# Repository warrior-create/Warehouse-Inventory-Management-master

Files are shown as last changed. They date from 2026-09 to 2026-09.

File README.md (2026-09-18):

# 🏭 Warehouse Inventory Management Robot

<div align="center">








**Problem Statement : Autonomous Inventory Management**

*A 4WD Mecanum Robot for Autonomous Navigation, QR Scanning, and Real-Time Inventory Logging*

</div>

---

## 📹 Demo Videos

<!-- 
INSTRUCTIONS: Replace the placeholder paths below with your actual video files or YouTube links.
For local files: Place videos in a 'media/' folder and use relative paths.
For YouTube: Use the embed format shown in the comments.
-->

<div align="center">

| 🎬 Hardware Navigation | 🤖 MPPI Controller |
|:---:|:---:|
| Hardware Navigation (https://drive.google.com/file/d/1SxE7VbpoMyJDe-7mRSphyiXIrN796s2v/view?usp=sharing) | MPPI Demo (https://drive.google.com/file/d/1yMgr9xhQmlWIOJ6BMVuErapGLEkPWAD1/view?usp=sharing) |
| [Watch Video](https://drive.google.com/file/d/1SxE7VbpoMyJDe-7mRSphyiXIrN796s2v/view?usp=sharing) | [Watch Video](https://drive.google.com/file/d/1yMgr9xhQmlWIOJ6BMVuErapGLEkPWAD1/view?usp=sharing) |

| 📱 QR Code Scanning | 🛡️ Optical Flow Safety |
|:---:|:---:|
| QR Scanning (https://drive.google.com/file/d/1jlzJpVaomlOkv6ThRwU9cso8ifu2L015/view?usp=sharing) | Optical Flow (https://drive.google.com/file/d/19zjg4Hd4r4iTfHF7JOrHWgnWNKGa0Jsm/view?usp=sharing) |
| [Watch Video](https://drive.google.com/file/d/1jlzJpVaomlOkv6ThRwU9cso8ifu2L015/view?usp=sharing) | [Watch Video](https://drive.google.com/file/d/19zjg4Hd4r4iTfHF7JOrHWgnWNKGa0Jsm/view?usp=sharing) |

</div>

---

## 📸 Project Gallery

<div align="center">

### 🤖 Robot Overview
<a href="https://drive.google.com/file/d/12Bs6bJ0aVyArBRewj-XbltesIlnt_Ru9/view?usp=sharing">
  Robot Front View
</a>

<br/><br/>

### 🏗️ Scissor Lift Mechanism
<a href="https://drive.google.com/file/d/1eT09PdCcN59-oF_Ee70JCgp37965IalH/view?usp=sharing">
  Scissor Lift Side View
</a>

</div>

---

## 📊 Presentation & Architecture

<div align="center">

📑 **[View Our Presentation](https://docs.google.com/presentation/d/1cAEmNjcDwh8xOOG8gRH6w87--OZm0wdz/edit?slide=id.p1#slide=id.p1)**

*Complete system architecture, design decisions, and implementation details*

</div>

---

## ✨ Highlights

| Feature | Description |
|---|---|
| 🚗 **4WD Mecanum Drive** | Omnidirectional movement with custom SolidWorks URDF |
| 🗺️ **Google Cartographer SLAM** | Dual-config strategy for mapping & navigation |
| 📍 **Nav2 + MPPI Controller** | Optimized for mecanum kinematics |
| 📷 **QR Detection** | CLAHE + Histogram Equalization + ZBar |
| 🛡️ **Optical Flow Safety** | Real-time intrusion detection for lift mechanism |
| 🌐 **Web GUI** | Next.js dashboard with virtual joystick |
| ☁️ **Cloud Database** | Neon (PostgreSQL) for inventory storage |
| 🔧 **ESP32 Control** | Custom firmware for NEMA23 steppers |

---

## 🏗️ System Architecture

```mermaid
%%{init: {'theme': 'neutral', 'themeVariables': { 'fontFamily': 'Inter, Arial', 'fontSize': '16px', 'primaryColor': '#f4f4f4', 'edgeLabelBackground':'#ffffff' }}}%%
graph TD
    classDef hardware fill:#e3f2fd,stroke:#1565c0,stroke-width:2px,color:#0d47a1;
    classDef ros fill:#e8f5e9,stroke:#2e7d32,stroke-width:2px,color:#1b5e20;
    classDef web fill:#fff3e0,stroke:#ef6c00,stroke-width:2px,color:#e65100;

    subgraph Hardware["🔧 Hardware Layer"]
        ESP1["ESP32 #1<br/>Front Motors"]:::hardware
        ESP2["ESP32 #2<br/>Back Motors"]:::hardware
        IMU["ICM-20948 IMU"]:::hardware
        LIDAR["RPLidar A1"]:::hardware
        CAM["USB Camera"]:::hardware
        LIFT["Lift Mechanism<br/>(PID + ToF)"]:::hardware
    end
    
    subgraph ROS2["🤖 ROS2 Layer"]
        HW["mecanum_hardware<br/>ros2_control"]:::ros
        NAV["navigation_setup<br/>Cartographer + Nav2"]:::ros
        QR["warehouse_rover_qr_detection<br/>ZBar + CLAHE"]:::ros
        DB["warehouse_rover_database<br/>Neon (Postgres)"]:::ros
        SAFETY["lift_safety<br/>Optical Flow"]:::ros
    end
    
    subgraph WebApp["🌐 Web Layer"]
        NEXT["Next.js Dashboard"]:::web
        JOY["Virtual Joystick"]:::web
        VIZ["3D Visualization"]:::web
    end
    
    ESP1 & ESP2 --> HW
    IMU --> HW
    LIDAR --> NAV
    CAM --> QR --> DB
    CAM --> SAFETY
    HW --> NAV
    NEXT <--> ROS2
    JOY --> HW
```

### TF Tree

```
map
 └── odom (AMCL in navigation / Cartographer in mapping)
      └── base_link (Cartographer sensor fusion)
           ├── imu_link
           ├── lidar_link
           ├── camera_link
           └── [wheel_frames × 4]
```

---

## 🛠️ Hardware Specifications

### Robot Platform

| Component | Specification |
|---|---|
| **Drive System** | 4WD Mecanum Wheels (100mm) |
| **Motors** | 4× NEMA23 Stepper Motors |
| **Motor Drivers** | TB6600 / DM556 |
| **Controllers** | 2× ESP32 (Serial @ 115200 baud) |
| **Main Computer** | Raspberry Pi 5 (4GB) → *Pi 4 (2GB) during demo* |
| **LiDAR** | RPLidar A1 (360° @ 5.5 Hz) |
| **Camera** | USB Camera (640×480) |
| **IMU** | ICM-20948 (9-axis) |
| **Lift Sensor** | VL53L0X ToF Laser |

### Wiring Diagram

```mermaid
%%{init: {'theme': 'neutral'}}%%
graph TD
    classDef pi fill:#d32f2f,stroke:#b71c1c,stroke-width:2px,color:white;
    classDef sensor fill:#fff9c4,stroke:#fbc02d,stroke-width:2px;
    classDef driver fill:#e0e0e0,stroke:#616161,stroke-width:2px;

    PI[Raspberry Pi 5]:::pi
    
    subgraph USB["USB Connections"]
        ESP1[ESP32 #1<br/>Front Motors]:::driver
        ESP2[ESP32 #2<br/>Back Motors]:::driver
        LIDAR[RPLidar A1]:::sensor
    end
    
    subgraph I2C["I2C Bus (GPIO)"]
        IMU[ICM-20948]:::sensor
    end
    
    subgraph Motors["Actuators"]
        M_FL[Front Left]
        M_FR[Front Right]
        M_BL[Back Left]
        M_BR[Back Right]
    end

    PI -->|/dev/ttyUSB0| ESP1
    PI -->|/dev/ttyUSB1| ESP2
    PI -->|/dev/ttyUSB2| LIDAR
    PI -->|SDA/SCL| IMU
    
    ESP1 --> M_FL & M_FR
    ESP2 --> M_BL & M_BR
```

---

## 📦 ROS2 Packages

### Package Overview

| Package | Language | Purpose |
|---|---|---|
| `mecanum_hardware` | C++ | ros2_control hardware interface for ESP32 + IMU |
| `mecanum_in_gazebo` | XML/Python | Gazebo simulation with full URDF |
| `navigation_setup` | Lua/Python | Cartographer SLAM + Nav2 configuration |
| `warehouse_rover_qr_detection` | C++ | ZBar-based QR code detection |
| `warehouse_rover_image_processing` | C++ | CLAHE + CUDA/CPU image preprocessing |
| `warehouse_rover_database` | Python | Neon (Postgres) cloud storage integration |
| `warehouse_rover_rack_detection` | C++ | Warehouse rack detection |
| `lift_safety` | Python | Optical flow intrusion detection |
| `warehouse_rover_msgs` | ROS2 IDL | Custom message definitions |

---

## 🗺️ Navigation Stack

### The Journey: From EKF Pain to Cartographer Success

We initially used **SLAM Toolbox + EKF** but faced severe challenges:

- ❌ Odometry drift
- ❌ Distorted maps  
- ❌ Unstable localization
- ❌ Poor fusion with only IMU + wheel odometry

**Solution: Google Cartographer**

Cartographer directly consumes `/imu`, `/scan`, and `/odom` and handles fusion internally. No EKF configuration pain!

### Dual Cartographer Configuration Strategy

We use **two separate Lua configurations** to avoid TF conflicts:

| Mode | Config File | TF Published | Use Case |
|---|---|---|---|
| **Mapping** | `cartographer_mapping.lua` | `map → odom → base_link` | Building new maps |
| **Navigation** | `cartographer_odom.lua` | `odom → base_link` only | Autonomous driving |

**Why?** In navigation mode, both AMCL and Cartographer would try to publish `map → odom`. Our solution: Cartographer handles sensor fusion only, AMCL handles localization.

### MPPI Controller for Mecanum

DWB (Dynamic Window Based) controller didn't work well for mecanum. Switching to **MPPI (Model Predictive Path Integral)** finally gave us smooth omnidirectional navigation.

### Automatic Waypoint Generation

We used **OpenCV** to auto-generate waypoints from the occupancy grid map:

```python
# Simplified approach
contours = cv2.findContours(map_image, ...)
waypoints = extract_rack_positions(contours)
```

---

## 📷 Image Processing Pipeline

Our QR detection pipeline uses multiple enhancement techniques for robust detection under varying lighting:

```mermaid
graph LR
    A["Raw Image"] --> B["CLAHE<br/>(Contrast Enhancement)"]
    B --> C["Histogram<br/>Equalization"]
    C --> D["Gaussian Blur<br/>(Noise Reduction)"]
    D --> E["ZBar<br/>QR Detection"]
    E --> F["Parse & Validate"]
    F --> G["Neon DB<br/>(Postgres)"]
```

### CLAHE (Contrast Limited Adaptive Histogram Equalization)

```cpp
cv::Ptr<cv::CLAHE> clahe = cv::createCLAHE(2.0, cv::Size(8, 8));
clahe->apply(gray_image, enhanced);
```

## 🛡️ Lift Safety System

The lifting mechanism includes an **optical flow-based safety system** to detect intrusions:

### How It Works

1. **Capture** continuous frames from camera
2. **Calculate** dense optical flow (Farneback algorithm)
3. **Detect** motion that isn't vertical (lift movement)
4. **Stop** immediately if foreign object detected

```python
# Dense Optical Flow Detection
flow = cv2.calcOpticalFlowFarneback(prev_frame, next_frame, ...)
mag, ang = cv2.cartToPolar(flow[..., 0], flow[..., 1])

# Ignore vertical motion (lift going up/down)
ignore_up = (ang > 65) & (ang < 115)
ignore_down = (ang > 245) & (ang < 295)

# Any other motion = intrusion!
alarm_mask = motion_mask & (~ignore_up) & (~ignore_down)
```

**Safety Feature:** If you put your hand (or any object) in the lift path, it **stops immediately**.

---

## 🌐 Web-Based GUI

Built with **Next.js 14** for modern, responsive control from any device on the same WiFi network.

### Features

| Component | Description |
|---|---|
| `WarehouseRoverDashboard` | Main dashboard with telemetry |
| `SimpleLaunchControl` | One-click ROS2 launch management |
| `virtual-joystick` | Touch-based robot control |
| `three-d-rover` | 3D WebGL robot visualization |
| `telemetry-chart` | Real-time sensor graphs |
| `mission-launch-sequence` | Animated mission startup |

### Starting the Web GUI

```bash
cd my-app/my-app
npm install
npm run dev
# Open http://localhost:3000
```

---

## ☁️ Database Integration

### Neon (PostgreSQL) Cloud Storage

We replaced local storage with **Neon (Serverless PostgreSQL)** for robust, scalable inventory management:

```
┌─────────────────────────────────────────────────────────┐
│                    Neon (PostgreSQL)                    │
│  ┌──────────────────┐      ┌──────────────────────┐   │
│  │    missions      │      │     detections        │   │
│  │  - id (UUID)     │      │  - id (UUID)          │   │
│  │  - start_time    │      │  - mission_id (FK)    │   │
│  │  - end_time      │      │  - rack_id            │   │
│  │  - status        │      │  - item_code          │   │
│  │  - total_items   │      │  - confidence         │   │
│  └──────────────────┘      │  - timestamp          │   │
│                            └──────────────────────┘   │
└─────────────────────────────────────────────────────────┘
```

### Detection Data Schema

```sql
CREATE TABLE detections (
    id UUID PRIMARY KEY DEFAULT gen_random_uuid(),
    mission_id UUID REFERENCES missions(id),
    rack_id VARCHAR(50),
    shelf_id VARCHAR(50),
    item_code VARCHAR(100),
    confidence FLOAT,
    timestamp TIMESTAMPTZ DEFAULT NOW()
);
```

### Why Neon?

- **Serverless**: Scales to zero when robot is idle
- **Branching**: Easy to split database for dev/test/prod environments
- **Performance**: High-speed queries for real-time inventory dashboards

---

## 🔧 ESP32 Firmware

### Communication Protocol

**Command Format (ROS2 → ESP32):**
```
V,<steps_per_sec_motor1>,<steps_per_sec_motor2>\n
```

**Example:**
```
V,400,-300\n  # Motor 1: 400 steps/s forward, Motor 2: 300 steps/s backward
```

**ESP32 Assignment:**

| ESP32 | Motors | Serial Port |
|---|---|---|
| ESP32 #1 | Front Left + Front Right | `/dev/ttyUSB0` |
| ESP32 #2 | Back Left + Back Right | `/dev/ttyUSB1` |

### Features

- ✅ Acceleration limiting (2000 steps/s²)
- ✅ Watchdog timer (500ms timeout)
- ✅ Emergency stop support
- ✅ Status reporting

---

## 🚀 Quick Start

### Prerequisites

```bash
# ROS2 Humble
sudo apt install ros-humble-desktop

# Dependencies
sudo apt install ros-humble-cartographer-ros ros-humble-nav2-bringup \
    ros-humble-ros2-control ros-humble-ros2-controllers \
    libzbar-dev python3-pymongo
```

### Clone & Build

```bash
git clone https://github.com/anishk85/WareHouse-Inventory-Management-.git
cd WareHouse-Inventory-Management-/src
colcon build
source install/setup.bash
```

### Launch Simulation

```bash
# Terminal 1: Gazebo
ros2 launch mecanum_in_gazebo gazebo.launch.py

# Terminal 2: Navigation
ros2 launch navigation_setup cartographer_mapping.launch.py use_sim:=true

# Terminal 3: Teleop
ros2 run mecanum_in_gazebo mecanum_teleop_key.py
```

### Launch Hardware (Raspberry Pi)

```bash
# Mapping mode
ros2 launch mecanum_hardware hardware_mapping.launch.py

# Navigation mode (with saved map)
ros2 launch mecanum_hardware hardware_navigation.launch.py \
    map:=/path/to/saved_map.yaml
```

---

## 🌿 Branches

| Branch | Purpose |
|---|---|
| `main` | Primary development branch |
| `hardware-2` | Hardware-specific optimizations for Raspberry Pi deployment |

---

## 📖 The Journey

<details>
<summary><b>Click to expand our 1.5-month journey</b></summary>

### The Challenge

- ⏰ **1.5 months** of development
- 📚 End-semester exams running parallel
- 😴 Sleeping at 2 AM, waking up at 4 AM
- 💪 Sleepless nights of debugging

### URDF Struggles

Mecanum wheels were the real challenge. Force-based control was common, but defining a **correct URDF for mecanum wheels** was the hard part. We:

1. Studied existing URDFs
2. Understood roller and wheel frames
3. Redefined everything in **SolidWorks**
4. Finally got a clean URDF pipeline

### Simulator Wars

We initially blamed the simulator. Gazebo physics felt unreliable, so we moved to **MuJoCo**, but the issues stayed. The problem wasn't the simulator—it was our odometry fusion.

### The EKF Nightmare

SLAM Toolbox + EKF gave us:
- Odometry drift
- Distorted maps
- Unstable localization

Even after heavy EKF tuning, results were poor because we only had IMU + wheel odometry (and wheel odometry was mirrored since steppers are accurate).

### Cartographer Saves the Day

Switching to **Google Cartographer** changed everything. It directly consumes `/imu`, `/scan`, and `/odom` and handles fusion internally. No EKF pain!

We later moved to a **dual Cartographer setup**, and most simulation tasks were completed.

### Hardware Transition

Because of clean software architecture, we set up low-level control in **2 days**, and within **3-4 days**, the robot was navigating!

### EMI Issues

Ports on Raspberry Pi 5 started swapping randomly. We fixed this using:
- Aluminum foil shielding
- Separate power lines

### The Disaster

**5 hours before the final demo**, a power fault burned our:
- 🔥 Raspberry Pi 5
- 🔥 LiDAR

No spare Pi 5 available. We shifted the entire stack to **Raspberry Pi 4 (2 GB RAM)**.

From scratch. Docker. Build. Using swap memory, we managed to show a working Nav2 stack.

### The Result

During the demo, the robot scanned **12 out of 15 QR codes**. The architecture and navigation impressed the judges.

**🥉 Bronze Medal!**

</details>

---

## 📊 Results

| Metric | Value |
|---|---|
| **QR Codes Scanned** | 12 / 15 (80%) |
| **Navigation Success** | Autonomous navigation demonstrated |
| **Final Position** | 🥉 Bronze Medal (3rd Place) |

---

## 📄 License

This project is licensed under the Apache 2.0 License - see the [LICENSE](LICENSE) file for details.

---

## 🙏 Acknowledgments

- The ROS2 community
- All open-source contributors

---

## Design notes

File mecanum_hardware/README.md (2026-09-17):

# Mecanum Hardware Package

ROS2 hardware interface for mecanum robot with NEMA23 stepper motors, ESP32 controllers, and IMU sensor fusion.

## Overview

This package provides the **ros2_control** hardware interface for controlling a mecanum wheel robot with:
- 4× NEMA23 stepper motors
- 2× ESP32 microcontrollers (serial communication)
- IMU sensor (I2C connection)
- Sensor fusion (70% IMU, 30% wheel odometry)

## Package Structure

```
mecanum_hardware/
├── config/
│   ├── hardware_controllers.yaml    # Controller config (50 Hz)
│   ├── lidar.yaml                    # RPLidar settings
│   ├── imu.yaml                      # IMU filter parameters
│   └── camera.yaml                   # RealSense camera (optional)
├── firmware/
│   └── esp32_stepper_controller/    # Arduino firmware for ESP32
│       └── esp32_stepper_controller.ino
├── include/mecanum_hardware/
│   └── mecanum_stepper_interface.hpp # Hardware interface header
├── launch/
│   ├── hardware.launch.py            # Base hardware + sensors
│   ├── hardware_mapping.launch.py    # Mapping mode
│   └── hardware_navigation.launch.py # Navigation mode
├── scripts/
│   └── imu_publisher_node.py         # IMU data publisher
├── src/
│   └── mecanum_stepper_interface.cpp # Hardware interface implementation
└── CMakeLists.txt
```

## Hardware Interface

### Class: `MecanumStepperInterface`

Implements `hardware_interface::SystemInterface` for ros2_control.

**Features**:
- Dual ESP32 serial communication (115200 baud)
- IMU sensor fusion (complementary filter)
- Wheel odometry calculation
- Slip detection (IMU vs wheel discrepancy)
- Hardware lifecycle management

**Control Loop**: 50 Hz update rate

**Topics Published**:
- `/mecanum_drive_controller/odom` (nav_msgs/Odometry) - Fused odometry

**Topics Subscribed**:
- `/imu/data` (sensor_msgs/Imu) - Raw IMU data (RELIABLE QoS)

### ESP32 Communication Protocol

**Command Format** (Hardware Interface → ESP32):
```
V,<steps_per_sec_motor1>,<steps_per_sec_motor2>\n
```

**Example**:
```
V,400,-300\n  # Motor 1: 400 steps/s forward, Motor 2: 300 steps/s backward
```

**Status Request**:
```
STATUS\n
```

**Response Format** (ESP32 → Hardware Interface):
```
ESP<id>:M1=<steps1>,M2=<steps2>\n
```

**Emergency Stop**:
```
STOP\n
```

### ESP32 Assignment

| ESP32 | Motors | Serial Port | Firmware Setting |
|---|---|---|---|
| ESP32 #1 | Front Left + Front Right | `/dev/ttyUSB0` | `ESP_ID = 1` |
| ESP32 #2 | Back Left + Back Right | `/dev/ttyUSB1` | `ESP_ID = 2` |

## Configuration

### hardware_controllers.yaml

```yaml
controller_manager:
  ros__parameters:
    update_rate: 50  # Hz

mecanum_drive_controller:
  ros__parameters:
    # Wheel parameters
    wheel_radius: 0.05                    # meters
    wheel_separation_x: 0.25              # meters (front-back)
    wheel_separation_y: 0.30              # meters (left-right)
    
    # Velocity limits
    linear.x.max_velocity: 0.5            # m/s
    linear.y.max_velocity: 0.5            # m/s
    angular.z.max_velocity: 1.0           # rad/s
    
    # Acceleration limits
    linear.x.max_acceleration: 0.5        # m/s²
    linear.y.max_acceleration: 0.5        # m/s²
    angular.z.max_acceleration: 1.0       # rad/s²
    
    # Safety
    cmd_vel_timeout: 0.5                  # seconds
```

### URDF Parameters

Defined in `mec_rob.ros2_control.hardware.xacro`:

```xml
<param name="esp1_port">/dev/ttyUSB0</param>
<param name="esp2_port">/dev/ttyUSB1</param>
<param name="steps_per_revolution">200</param>
<param name="wheel_radius">0.05</param>
<param name="gear_ratio">1.0</param>
<param name="wheel_separation_x">0.25</param>
<param name="wheel_separation_y">0.30</param>
<param name="use_imu">true</param>
```

## Launch Files

### 1. hardware.launch.py

**Purpose**: Launch base hardware interface with all sensors

**Usage**:
```bash
ros2 launch mecanum_hardware hardware.launch.py \
  esp1_port:=/dev/ttyUSB0 \
  esp2_port:=/dev/ttyUSB1 \
  lidar_port:=/dev/ttyUSB2 \
  use_depth_camera:=false
```

**Nodes Launched**:
- `robot_state_publisher` - Publishes robot TF tree from URDF
- `controller_manager` - ros2_control manager
- `joint_state_broadcaster` - Publishes joint states
- `mecanum_drive_controller` - Mecanum kinematics controller
- `rplidar_node` - LiDAR driver
- `imu_filter_madgwick_node` - IMU orientation filter
- `imu_publisher_node` - Raw IMU data from GPIO
- `realsense2_camera_node` - Depth camera (if enabled)

**Launch Sequence**:
- t=0s: Robot state publisher + ros2_control
- t=2s: Controllers (broadcaster, mecanum)
- t=4s: Sensors (LiDAR, IMU filter)
- t=5s: IMU publisher, camera

### 2. hardware_mapping.launch.py

**Purpose**: SLAM mapping mode to build environment maps

**Usage**:
```bash
ros2 launch mecanum_hardware hardware_mapping.launch.py \
  esp1_port:=/dev/ttyUSB0 \
  esp2_port:=/dev/ttyUSB1 \
  lidar_port:=/dev/ttyUSB2
```

**Additional Nodes**:
- `cartographer_node` - SLAM with sensor fusion
- `cartographer_occupancy_grid_node` - Generates occupancy grid map

**Cartographer Config**: `cartographer_mapping.lua`
- Publishes: `map → odom → base_link`
- Fuses: IMU + wheel odometry + LiDAR scan

**TF Tree**:
```
map → odom → base_link → [sensors, wheels]
└─── All published by Cartographer ────┘
```

**Save Map**:
```bash
ros2 run nav2_map_server map_saver_cli -f ~/my_map
```

### 3. hardware_navigation.launch.py

**Purpose**: Autonomous navigation with saved map

**Usage**:
```bash
ros2 launch mecanum_hardware hardware_navigation.launch.py \
  map:=/path/to/my_map.yaml \
  esp1_port:=/dev/ttyUSB0 \
  esp2_port:=/dev/ttyUSB1 \
  lidar_port:=/dev/ttyUSB2
```

**Additional Nodes**:
- `cartographer_node` - Odometry sensor fusion
- `amcl` - Monte Carlo localization on saved map
- `map_server` - Serves saved map
- `planner_server` - Global path planning
- `controller_server` - Local trajectory control
- `recoveries_server` - Recovery behaviors
- `bt_navigator` - Behavior tree navigation

**Cartographer Config**: `cartographer_odom.lua`
- Publishes: `odom → base_link` only
- AMCL publishes: `map → odom`

**TF Tree**:
```
map → odom → base_link → [sensors, wheels]
(AMCL) (Cartographer)
```

## IMU Publisher Node

**Script**: `scripts/imu_publisher_node.py`

**Purpose**: Read IMU data from I2C GPIO and publish to ROS2

**Supported IMUs**:
- MPU6050 (I2C address: 0x68)
- BNO055 (I2C address: 0x28)

**Topic**: `/imu/data_raw` (sensor_msgs/Imu)

**Frequency**: 100 Hz

**I2C Connection**:
- SDA: GPIO 2 (Pin 3)
- SCL: GPIO 3 (Pin 5)
- VCC: 3.3V (Pin 1)
- GND: GND (Pin 6)

**Enable I2C**:
```bash
sudo raspi-config
# Interface Options → I2C → Enable
sudo reboot
```

**Test I2C**:
```bash
i2cdetect -y 1
# Should show 0x68 (MPU6050) or 0x28 (BNO055)
```

**Dependencies**:
```bash
pip3 install adafruit-circuitpython-mpu6050
pip3 install adafruit-circuitpython-bno055
```

## ESP32 Firmware

**Location**: `firmware/esp32_stepper_controller/esp32_stepper_controller.ino`

**Flash Instructions**:
1. Install Arduino IDE with ESP32 board support
2. Open `esp32_stepper_controller.ino`
3. Set `ESP_ID = 1` for front motors, `ESP_ID = 2` for back motors
4. Configure pin mappings if needed
5. Upload to ESP32

**Pin Configuration** (Default):

**Motor 1** (Left):
- STEP: GPIO 12
- DIR: GPIO 14
- ENABLE: GPIO 27

**Motor 2** (Right):
- STEP: GPIO 26
- DIR: GPIO 25
- ENABLE: GPIO 33

**Features**:
- Acceleration limiting (2000 steps/s²)
- Watchdog timer (500ms timeout)
- Emergency stop support
- Status reporting

## Testing

### Test Hardware Interface
```bash
# Launch hardware
ros2 launch mecanum_hardware hardware.launch.py

# Check controllers
ros2 control list_controllers

# Should show:
# joint_state_broadcaster [active]
# mecanum_drive_controller [active]

# Test movement (wheels off ground!)
ros2 topic pub /cmd_vel geometry_msgs/Twist \
  '{linear: {x: 0.1}}' --rate 1
```

### Test ESP32 Communication
```bash
# Find ESP32 ports
ls -l /dev/ttyUSB*

# Test ESP1
echo "STATUS" > /dev/ttyUSB0
cat /dev/ttyUSB0

# Should respond: ESP1:M1=0,M2=0
```

### Test IMU
```bash
# Check I2C
i2cdetect -y 1

# Launch IMU publisher
ros2 run mecanum_hardware imu_publisher_node.py

# Monitor IMU data
ros2 topic echo /imu/data_raw
ros2 topic hz /imu/data_raw  # Should be ~100 Hz
```

## Troubleshooting

### Problem: Controllers not loading
**Solution**: Check USB port permissions
```bash
sudo chmod 666 /dev/ttyUSB*
```

### Problem: IMU not detected
**Solution**: Enable I2C and check wiring
```bash
sudo raspi-config  # Enable I2C
i2cdetect -y 1     # Verify detection
```

### Problem: Robot doesn't move
**Solution**: 
1. Check ESP32 power supply
2. Verify firmware is flashed with correct ESP_ID
3. Test ESP32 serial communication
4. Check motor driver enable pins

### Problem: Odometry drift
**Solution**: 
1. Enable IMU fusion: `use_imu: true` in URDF
2. Calibrate IMU orientation
3. Tune IMU fusion weight (default 70% IMU, 30% wheels)

### Problem: Nav2 doesn't start
**Solution**: Increase launch delays if Cartographer isn't ready
```python
# In hardware_navigation.launch.py
TimerAction(period=12.0, ...)  # Increase from 12s to 15s
```

## Related Documentation

- [HARDWARE_SETUP.md](../../HARDWARE_SETUP.md) - Complete setup guide
- [ARCHITECTURE.md](../../ARCHITECTURE.md) - System architecture
- [CARTOGRAPHER_CONFIGS.md](../../CARTOGRAPHER_CONFIGS.md) - Cartographer strategy
- [DEPLOYMENT_CHECKLIST.md](../../DEPLOYMENT_CHECKLIST.md) - Step-by-step deployment

## Dependencies

**ROS2 Packages**:
- `ros2_control`
- `ros2_controllers`
- `controller_manager`
- `hardware_interface`
- `cartographer_ros`
- `nav2_bringup`
- `rplidar_ros`
- `imu_filter_madgwick`
- `realsense2_camera` (optional)

**Python Libraries**:
- `adafruit-circuitpython-mpu6050`
- `adafruit-circuitpython-bno055`

**System**:
- Docker with privileged mode (hardware access)
- I2C enabled (`raspi-config`)
- USB serial ports accessible

---

**Author**: Mecanum Robot Team  
**Last Updated**: November 2025  
**ROS2 Version**: Humble Hawksbill

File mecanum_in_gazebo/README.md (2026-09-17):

# Mecanum in Gazebo Package

Gazebo simulation package for the mecanum wheel robot with ROS2 Humble integration.

## Overview

This package provides a complete Gazebo simulation environment for testing the mecanum robot before hardware deployment. It includes physics simulation, sensor models, and ros2_control integration.

## Package Structure

```
mecanum_in_gazebo/
├── config/
│   ├── controllers.yaml          # Simulation controller config
│   └── ekf.yaml                   # Robot localization (optional)
├── launch/
│   ├── gazebo.launch.py          # Main simulation launcher
│   └── ekf.launch.py              # EKF sensor fusion (optional)
├── meshes/                        # 3D meshes for visualization
│   ├── base_link.stl
│   ├── wheel_frame_*.stl
│   └── roller_*.stl
├── scripts/
│   └── mecanum_teleop_key.py     # Keyboard teleoperation
├── urdf/
│   ├── mec_rob.xacro             # Main robot description
│   ├── mec_rob.ros2_control.xacro     # Simulation control
│   ├── mec_rob.ros2_control.hardware.xacro  # Hardware control
│   ├── mec_rob.gazebo            # Gazebo plugins
│   ├── mec_rob.trans             # Joint transformations
│   ├── lidar.xacro               # LiDAR sensor
│   ├── lidar.gazebo              # LiDAR Gazebo plugin
│   ├── depth_camera.xacro        # RealSense camera
│   ├── depth_camera.gazebo       # Camera Gazebo plugin
│   ├── imu.xacro                 # IMU sensor
│   ├── imu.gazebo                # IMU Gazebo plugin
│   └── materials.xacro           # Visual materials
├── worlds/
│   └── empty.world               # Gazebo world file
└── CMakeLists.txt
```

## Robot Description (URDF)

### Main URDF: `mec_rob.xacro`

The robot URDF supports **conditional compilation** for simulation vs hardware:

```xml
<!-- Arguments -->
<xacro:arg name="use_sim" default="true"/>
<xacro:arg name="use_depth_camera" default="true"/>

<!-- Simulation mode -->
<xacro:if value="$(arg use_sim)">
  <xacro:include filename="mec_rob.ros2_control.xacro"/>
  <xacro:include filename="lidar.gazebo"/>
  <xacro:include filename="depth_camera.gazebo"/>
  <xacro:include filename="imu.gazebo"/>
</xacro:if>

<!-- Hardware mode -->
<xacro:unless value="$(arg use_sim)">
  <xacro:include filename="mec_rob.ros2_control.hardware.xacro"/>
</xacro:unless>
```

**Usage**:
```bash
# Simulation
ros2 launch mecanum_in_gazebo gazebo.launch.py use_sim:=true

# Hardware
ros2 launch mecanum_hardware hardware.launch.py use_sim:=false
```

### Robot Specifications

**Base Dimensions**:
- Length: 0.30 m
- Width: 0.40 m
- Height: 0.15 m
- Mass: 19.35 kg

**Wheels**:
- Type: Mecanum (with rollers)
- Radius: 0.05 m (50 mm)
- Width: 0.05 m
- Configuration: 4-wheel independent (FL, FR, BL, BR)
- Joint Type: Continuous rotation

**Wheel Separation**:
- X-axis (front-back): 0.25 m
- Y-axis (left-right): 0.30 m

**Sensors**:
- LiDAR: RPLidar A1 (360°, 0-12m range)
- IMU: Simulated 6-DOF (100 Hz)
- Depth Camera: RealSense D435 (640×480, optional)

## Gazebo Simulation

### Launch Gazebo

```bash
# Basic launch
ros2 launch mecanum_in_gazebo gazebo.launch.py

# With depth camera disabled
ros2 launch mecanum_in_gazebo gazebo.launch.py use_depth_camera:=false

# Pause at start
ros2 launch mecanum_in_gazebo gazebo.launch.py pause:=true
```

**What happens**:
1. Gazebo GUI opens with empty world
2. Robot spawns at origin (0, 0, 0)
3. Controllers load (takes ~10 seconds):
   - `joint_state_broadcaster` - Publishes joint states
   - `mecanum_drive_controller` - Mecanum kinematics
4. `cmd_vel_bridge` starts - Converts Twist → TwistStamped
5. Sensors start publishing data

### Gazebo Plugins

**1. Differential Drive Plugin** (disabled, using ros2_control):
```xml
<!-- In mec_rob.gazebo -->
<!-- libgazebo_ros_diff_drive.so - NOT USED -->
```

**2. ros2_control Plugin** (active):
```xml
<plugin filename="libgazebo_ros2_control.so" name="gazebo_ros2_control">
  <parameters>$(find mecanum_in_gazebo)/config/controllers.yaml</parameters>
</plugin>
```

**3. Sensor Plugins**:
- **LiDAR**: `libgazebo_ros_ray_sensor.so`
  - Topic: `/scan`
  - Rate: 10 Hz
  - Range: 0.15-12.0 m
  
- **IMU**: `libgazebo_ros_imu_sensor.so`
  - Topic: `/imu/data`
  - Rate: 100 Hz
  - Outputs: Linear acceleration, angular velocity, orientation
  
- **Depth Camera**: `libgazebo_ros_camera.so`
  - Topics: `/camera/color/image_raw`, `/camera/depth/image_raw`
  - Resolution: 640×480
  - FPS: 30

## Controllers Configuration

### File: `config/controllers.yaml`

```yaml
controller_manager:
  ros__parameters:
    update_rate: 100  # Hz (simulation can handle higher rate)

joint_state_broadcaster:
  ros__parameters:
    publish_rate: 50.0

mecanum_drive_controller:
  ros__parameters:
    # Joint names
    front_left_wheel_joint: front_left_joint
    front_right_wheel_joint: front_right_joint
    back_left_wheel_joint: back_left_joint
    back_right_wheel_joint: back_right_joint
    
    # Kinematics
    wheel_radius: 0.05                # meters
    wheel_separation_x: 0.25          # front-back distance
    wheel_separation_y: 0.30          # left-right distance
    
    # TF Publishing
    enable_odom_tf: true              # Publish odom → base_link
    odom_frame_id: odom
    base_frame_id: base_link
    
    # Velocity limits
    linear.x.max_velocity: 1.0        # m/s
    linear.y.max_velocity: 1.0        # m/s
    angular.z.max_velocity: 2.0       # rad/s
```

### Controller Types

**Joint State Broadcaster**:
- Publishes `/joint_states` topic
- Used by `robot_state_publisher` for TF tree

**Mecanum Drive Controller**:
- Subscribes: `/mecanum_drive_controller/reference` (TwistStamped)
- Publishes: `/mecanum_drive_controller/odom` (Odometry)
- Computes mecanum wheel inverse kinematics
- Publishes `odom → base_link` TF

## Teleoperation

### Keyboard Control

```bash
ros2 run mecanum_in_gazebo mecanum_teleop_key.py
```

**Controls**:
```
Moving around:
   u    i    o
   j    k    l
   m    ,    .

u/o: Forward + rotate
i  : Forward
j/l: Rotate left/right
k  : Stop
m/.: Backward + rotate
,  : Backward

q/z: Increase/decrease max speeds by 10%
w/x: Increase/decrease only linear speed by 10%
e/c: Increase/decrease only angular speed by 10%

CTRL-C to quit
```

**Current Speed Display**:
```
currently:	speed 0.5	turn 1.0
```

### Manual Command Publishing

```bash
# Forward
ros2 topic pub /cmd_vel geometry_msgs/Twist '{linear: {x: 0.3}}' -r 1

# Strafe right
ros2 topic pub /cmd_vel geometry_msgs/Twist '{linear: {y: 0.3}}' -r 1

# Rotate counterclockwise
ros2 topic pub /cmd_vel geometry_msgs/Twist '{angular: {z: 0.5}}' -r 1

# Diagonal movement (forward-right + rotate)
ros2 topic pub /cmd_vel geometry_msgs/Twist \
  '{linear: {x: 0.3, y: 0.2}, angular: {z: 0.3}}' -r 1
```

## cmd_vel_bridge Node

**Purpose**: Convert `Twist` messages to `TwistStamped` for the controller

**Source**: Built-in node in launch file

```python
Node(
    package='ros_gz_bridge',
    executable='parameter_bridge',
    name='cmd_vel_bridge',
    arguments=['/cmd_vel@geometry_msgs/msg/Twist@ignition.msgs.Twist'],
    remappings=[
        ('/cmd_vel', '/mecanum_drive_controller/reference')
    ]
)
```

**Data Flow**:
```
/cmd_vel (Twist) → cmd_vel_bridge → /mecanum_drive_controller/reference (TwistStamped)
```

## Robot Localization (EKF)

### Optional Sensor Fusion

**Launch**:
```bash
ros2 launch mecanum_in_gazebo ekf.launch.py
```

**Config**: `config/ekf.yaml`

**Purpose**: Fuses wheel odometry + IMU for better state estimation

**Settings**:
```yaml
ekf_filter_node:
  ros__parameters:
    frequency: 50.0
    publish_tf: false  # Disabled to avoid conflict with controller
    
    # Input sources
    odom0: /mecanum_drive_controller/odometry
    odom0_config: [false, false, false,  # x, y, z position
                   false, false, false,  # roll, pitch, yaw
                   true,  true,  false,  # x_vel, y_vel, z_vel
                   false, false, true,   # roll_vel, pitch_vel, yaw_vel
                   false, false, false]  # x_accel, y_accel, z_accel
    
    imu0: /imu/data_fixed
    imu0_config: [false, false, false,  # position
                  false, false, true,   # orientation (yaw only)
                  false, false, false,  # linear velocity
                  false, false, true,   # angular velocity (yaw rate)
                  true,  true,  false]  # linear acceleration (x, y)
```

**Output**: `/odometry/local` (Fused odometry)

**Note**: Currently `publish_tf: false` to avoid TF conflicts with `mecanum_drive_controller`.

## Topics Reference

### Published Topics

| Topic | Type | Rate | Description |
|---|---|---|---|
| `/joint_states` | sensor_msgs/JointState | 50 Hz | Wheel joint states |
| `/mecanum_drive_controller/odom` | nav_msgs/Odometry | 50 Hz | Raw wheel odometry |
| `/odom` | nav_msgs/Odometry | 50 Hz | Processed odometry |
| `/odometry/local` | nav_msgs/Odometry | 50 Hz | EKF fused (if running) |
| `/imu/data` | sensor_msgs/Imu | 100 Hz | Raw IMU |
| `/imu/data_fixed` | sensor_msgs/Imu | 100 Hz | IMU with covariances |
| `/scan` | sensor_msgs/LaserScan | 10 Hz | LiDAR scan |
| `/camera/color/image_raw` | sensor_msgs/Image | 30 Hz | RGB image |
| `/camera/depth/image_raw` | sensor_msgs/Image | 30 Hz | Depth image |
| `/tf` | tf2_msgs/TFMessage | Variable | Transform tree |

### Subscribed Topics

| Topic | Type | Description |
|---|---|---|
| `/cmd_vel` | geometry_msgs/Twist | Velocity commands (input) |
| `/mecanum_drive_controller/reference` | geometry_msgs/TwistStamped | Controller input |

## TF Tree

### Simulation TF Tree

```
odom
 └─ base_link (published by mecanum_drive_controller)
     ├─ imu_link
     ├─ lidar_link
     ├─ camera_link
     ├─ wheel_frame_FL_1
     ├─ wheel_frame_FR_1
     ├─ wheel_frame_BL_1
     └─ wheel_frame_BR_1
         └─ roller_* (36 rollers total)
```

**Publishers**:
- `odom → base_link`: `mecanum_drive_controller`
- `base_link → sensors/wheels`: `robot_state_publisher` (from URDF)

## Monitoring & Debugging

### Check System Status

```bash
# List nodes
ros2 node list

# Check controllers
ros2 control list_controllers

# Expected output:
# joint_state_broadcaster  [active]
# mecanum_drive_controller [active]

# View TF tree
ros2 run tf2_tools view_frames
evince frames.pdf

# Check topics
ros2 topic list
ros2 topic hz /scan
ros2 topic hz /imu/data
ros2 topic hz /mecanum_drive_controller/odom

# Echo odometry
ros2 topic echo /mecanum_drive_controller/odom

# Monitor transforms
ros2 run tf2_ros tf2_echo odom base_link
```

### RViz Visualization

```bash
# Launch RViz
rviz2

# Add displays:
# - RobotModel (shows URDF)
# - TF (transform tree)
# - LaserScan (/scan)
# - Odometry (/mecanum_drive_controller/odom)
# - Image (/camera/color/image_raw)
```

**RViz Configuration**:
- Fixed Frame: `odom`
- Robot Description: `/robot_description`

## Troubleshooting

### Problem: Robot doesn't move
**Causes**:
1. Controllers not active
2. cmd_vel_bridge not running
3. Wrong topic name

**Solutions**:
```bash
# Check controller status
ros2 control list_controllers

# Restart controllers if needed
ros2 control set_controller_state mecanum_drive_controller stop
ros2 control set_controller_state mecanum_drive_controller start

# Check if bridge is running
ros2 node list | grep bridge

# Verify topic connection
ros2 topic info /cmd_vel
ros2 topic info /mecanum_drive_controller/reference
```

### Problem: Gazebo crashes on launch
**Solution**: Increase Gazebo timeout
```python
# In gazebo.launch.py
gzserver_cmd = IncludeLaunchDescription(
    ...
    launch_arguments={'timeout': '60.0'}.items()  # Increase from default
)
```

### Problem: Controllers timeout
**Solution**: Increase controller load delay
```python
# In gazebo.launch.py
TimerAction(
    period=10.0,  # Increase from 2.0
    actions=[load_joint_state_broadcaster]
)
```

### Problem: TF tree errors
**Solution**: Check for multiple TF publishers
```bash
# Find TF publishers
ros2 topic info /tf

# Check EKF settings
# Set publish_tf: false in ekf.yaml if using controller TF
```

### Problem: Wheels slide in Gazebo
**Solution**: Adjust friction in URDF
```xml
<gazebo reference="wheel_frame_FL_1">
  <mu1>1.0</mu1>  <!-- Increase friction -->
  <mu2>1.0</mu2>
  <kp>1000000.0</kp>
  <kd>100.0</kd>
</gazebo>
```

## Testing Workflow

### 1. Basic Movement Test
```bash
# Terminal 1: Launch Gazebo
ros2 launch mecanum_in_gazebo gazebo.launch.py

# Terminal 2: Test keyboard control
ros2 run mecanum_in_gazebo mecanum_teleop_key.py

# Try all directions: forward, back, strafe, rotate, diagonal
```

### 2. Sensor Test
```bash
# Terminal 1: Gazebo

# Terminal 2: Monitor sensors
ros2 topic hz /scan
ros2 topic hz /imu/data
ros2 topic hz /camera/color/image_raw

# Terminal 3: Visualize in RViz
rviz2
```

### 3. Odometry Test
```bash
# Drive in square pattern
ros2 topic pub /cmd_vel geometry_msgs/Twist '{linear: {x: 0.5}}' -r 1
# Wait 2 seconds, stop, rotate 90°
ros2 topic pub /cmd_vel geometry_msgs/Twist '{angular: {z: 1.57}}' -r 1
# Repeat 4 times

# Check drift
ros2 topic echo /mecanum_drive_controller/odom
```

## Integration with Navigation

This simulation package integrates with:
- **Cartographer**: SLAM mapping
- **Nav2**: Autonomous navigation
- **AMCL**: Localization

See [navigation_setup](../navigation_setup/README.md) package for navigation configs.

## Related Documentation

- [Main README](../../README.md) - Project overview
- [mecanum_hardware](../mecanum_hardware/README.md) - Real hardware interface
- [navigation_setup](../navigation_setup/README.md) - Navigation configs
- [ARCHITECTURE.md](../../ARCHITECTURE.md) - System architecture

## Dependencies

**ROS2 Packages**:
- `gazebo_ros_pkgs`
- `ros2_control`
- `ros2_controllers`
- `controller_manager`
- `robot_state_publisher`
- `joint_state_publisher`
- `xacro`
- `robot_localization` (optional)

**System**:
- Gazebo 11 (comes with ROS2 Humble desktop)
- Ubuntu 22.04

---

**Author**: Mecanum Robot Team  
**Last Updated**: November 2025  
**ROS2 Version**: Humble Hawksbill

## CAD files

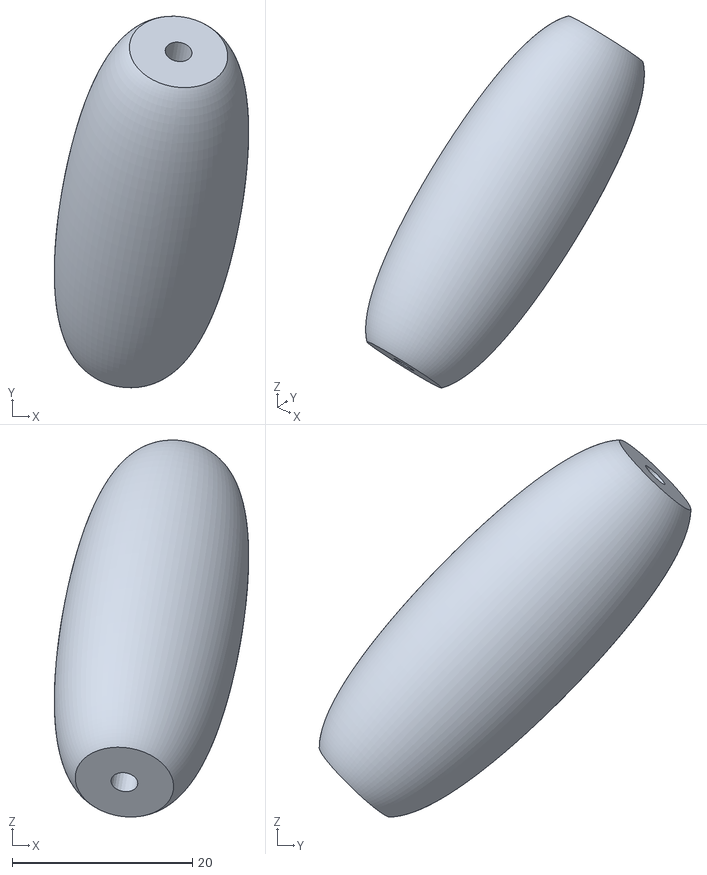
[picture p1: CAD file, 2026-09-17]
mecanum_in_gazebo/meshes/roller_33_1.stl
21.6 x 41.2 x 41.8

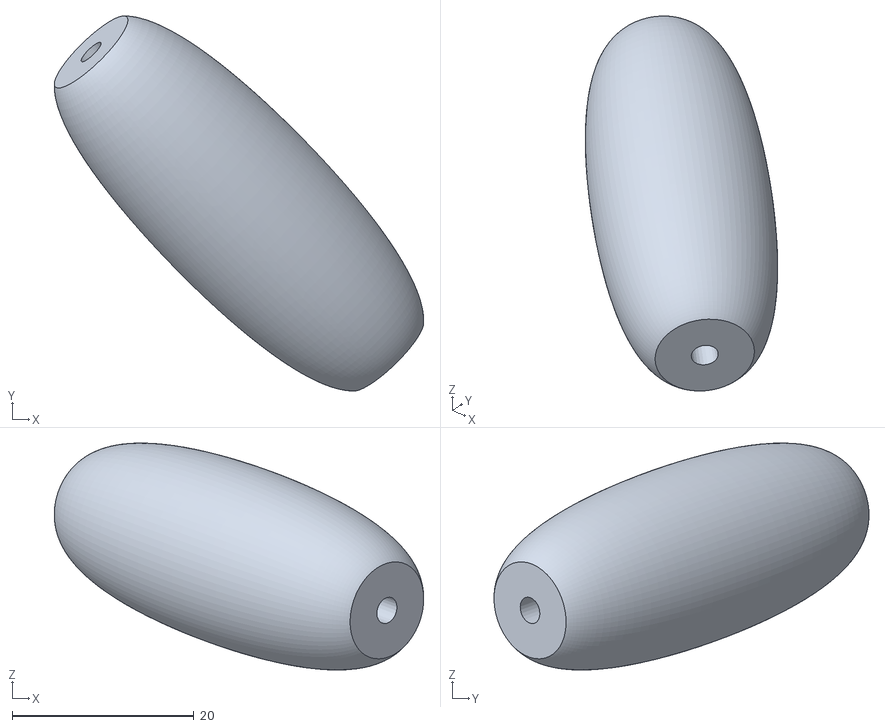
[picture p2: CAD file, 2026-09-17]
mecanum_in_gazebo/meshes/roller_35_1.stl
40.6 x 41.2 x 24.9

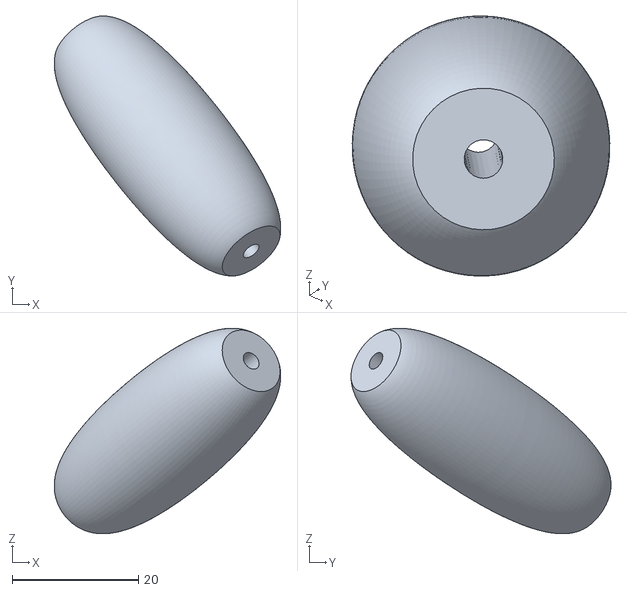
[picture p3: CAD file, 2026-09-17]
mecanum_in_gazebo/meshes/roller_2_1.stl
35.9 x 41.2 x 32.6

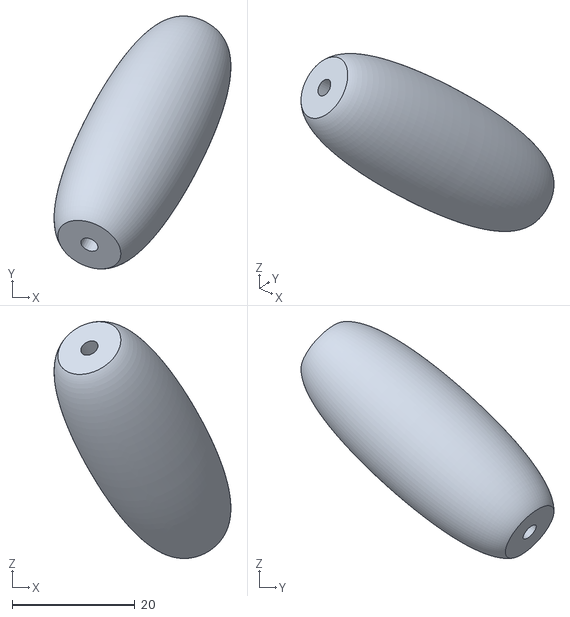
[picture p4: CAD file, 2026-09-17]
mecanum_in_gazebo/meshes/roller_4_1.stl
28.8 x 41.2 x 38.6

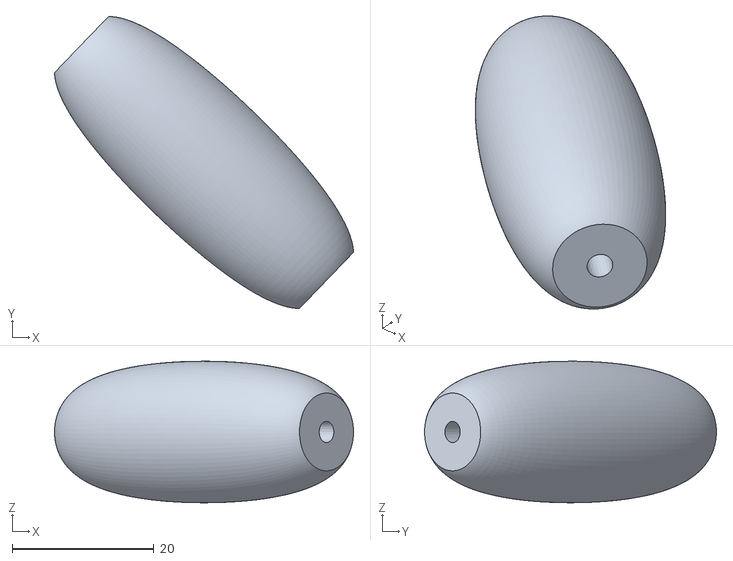
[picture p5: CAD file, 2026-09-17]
mecanum_in_gazebo/meshes/roller_7_1.stl
42.2 x 41.2 x 20.0

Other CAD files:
mecanum_in_gazebo/meshes/roller_1_1.stl
mecanum_in_gazebo/meshes/roller_3_1.stl
mecanum_in_gazebo/meshes/roller_10_1.stl
mecanum_in_gazebo/meshes/roller_28_1.stl
mecanum_in_gazebo/meshes/roller_24_1.stl
mecanum_in_gazebo/meshes/roller_27_1.stl
mecanum_in_gazebo/meshes/roller_25_1.stl
mecanum_in_gazebo/meshes/roller_11_1.stl
mecanum_in_gazebo/meshes/roller_5_1.stl
mecanum_in_gazebo/meshes/roller_12_1.stl
mecanum_in_gazebo/meshes/roller_14_1.stl
mecanum_in_gazebo/meshes/roller_16_1.stl
mecanum_in_gazebo/meshes/roller_23_1.stl
mecanum_in_gazebo/meshes/base_link.stl
mecanum_in_gazebo/meshes/roller_13_1.stl
mecanum_in_gazebo/meshes/roller_15_1.stl
mecanum_in_gazebo/meshes/roller_17_1.stl
mecanum_in_gazebo/meshes/roller_18_1.stl
mecanum_in_gazebo/meshes/roller_19_1.stl
mecanum_in_gazebo/meshes/roller_20_1.stl
mecanum_in_gazebo/meshes/roller_21_1.stl
mecanum_in_gazebo/meshes/roller_22_1.stl
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

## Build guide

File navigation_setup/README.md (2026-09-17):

# Navigation Setup Package

ROS2 navigation configuration for the mecanum robot using Cartographer SLAM and Nav2 autonomous navigation.

## Overview

This package provides complete navigation stack configuration including:
- **Cartographer**: SLAM and localization with sensor fusion
- **Nav2**: Path planning, obstacle avoidance, and behavior trees
- **AMCL**: Monte Carlo localization for saved maps
- **Map Server**: Serves pre-built maps for navigation

## Package Structure

```
navigation_setup/
├── config/
│   ├── cartographer_mapping.lua      # SLAM mapping config
│   ├── cartographer_odom.lua         # Odometry fusion config
│   ├── nav2_params.yaml              # Nav2 stack parameters
│   └── amcl_params.yaml              # AMCL localization (optional)
├── launch/
│   ├── cartographer_mapping.launch.py   # Mapping mode
│   ├── cartographer_navigation.launch.py # Navigation with AMCL
│   └── nav2_bringup.launch.py          # Nav2 stack only
├── maps/
│   ├── my_map.pgm                    # Saved map image
│   └── my_map.yaml                   # Map metadata
├── rviz/
│   ├── cartographer.rviz             # RViz config for mapping
│   └── navigation.rviz               # RViz config for navigation
└── CMakeLists.txt
```

## Cartographer Configuration

### Two-Config Strategy

This project uses **two separate Cartographer configurations** to avoid TF conflicts:

| Mode | Config File | TF Published | Use Case |
|---|---|---|---|
| **Mapping** | `cartographer_mapping.lua` | `map → odom → base_link` | Building new maps |
| **Navigation** | `cartographer_odom.lua` | `odom → base_link` only | Autonomous driving |

**Why?** 
- In navigation mode, both AMCL and Cartographer would try to publish `map → odom`
- Solution: Cartographer only does sensor fusion (`odom → base_link`), AMCL does localization (`map → odom`)

**See**: [CARTOGRAPHER_CONFIGS.md](../../CARTOGRAPHER_CONFIGS.md) for detailed explanation

### 1. cartographer_mapping.lua

**Purpose**: Full SLAM for building maps

**Key Settings**:
```lua
options = {
  map_frame = "map",
  published_frame = "base_link",
  odom_frame = "odom",
  provide_odom_frame = true,  -- Publishes full TF chain
  use_odometry = true,         -- Fuse wheel odometry
  
  num_laser_scans = 1,
  num_point_clouds = 0,
}

TRAJECTORY_BUILDER_2D.use_imu_data = true
TRAJECTORY_BUILDER_2D.imu_gravity_time_constant = 10.0
TRAJECTORY_BUILDER_2D.min_range = 0.15
TRAJECTORY_BUILDER_2D.max_range = 12.0
TRAJECTORY_BUILDER_2D.use_online_correlative_scan_matching = true

MAP_BUILDER.use_trajectory_builder_2d = true
MAP_BUILDER.num_background_threads = 4  # Use 2 for RPi5
```

**TF Chain**:
```
map → odom → base_link → [sensors, wheels]
└──── All published by Cartographer ────┘
```

**Topics**:
- Input: `/scan`, `/odom`, `/imu/data`
- Output: `/map` (occupancy grid), `/submap_list`, `/landmark_poses_list`
- TF: `map → odom → base_link`

**Launch**:
```bash
# Simulation
ros2 launch navigation_setup cartographer_mapping.launch.py use_sim:=true

# Hardware
ros2 launch mecanum_hardware hardware_mapping.launch.py
```

### 2. cartographer_odom.lua

**Purpose**: Sensor fusion for navigation (no mapping)

**Key Settings**:
```lua
options = {
  map_frame = "odom",           -- Cartographer's "map" is odom frame
  published_frame = "base_link",
  odom_frame = "odom",
  provide_odom_frame = true,    -- Publishes odom → base_link only
  use_odometry = true,
}

TRAJECTORY_BUILDER_2D.use_imu_data = true
TRAJECTORY_BUILDER_2D.use_online_correlative_scan_matching = true
```

**TF Chain**:
```
map → odom → base_link
(AMCL) (Cartographer)
```

**Topics**:
- Input: `/scan`, `/odom`, `/imu/data`
- Output: TF only (`odom → base_link`)

**Launch**:
```bash
# Always launched as part of navigation stack
ros2 launch mecanum_hardware hardware_navigation.launch.py map:=/path/to/map.yaml
```

## Nav2 Configuration

### File: `config/nav2_params.yaml`

Complete Nav2 stack configuration with:
- Global costmap
- Local costmap
- Path planners
- Controllers
- Behavior trees
- Recovery behaviors

**Key Parameters**:

**Global Costmap** (for path planning):
```yaml
global_costmap:
  global_costmap:
    ros__parameters:
      update_frequency: 1.0
      publish_frequency: 1.0
      global_frame: map
      robot_base_frame: base_link
      resolution: 0.05
      width: 10
      height: 10
      plugins: ["static_layer", "obstacle_layer", "inflation_layer"]
```

**Local Costmap** (for obstacle avoidance):
```yaml
local_costmap:
  local_costmap:
    ros__parameters:
      update_frequency: 5.0
      publish_frequency: 2.0
      global_frame: odom
      robot_base_frame: base_link
      resolution: 0.05
      width: 3
      height: 3
      plugins: ["voxel_layer", "inflation_layer"]
```

**Controller** (trajectory following):
```yaml
controller_server:
  ros__parameters:
    controller_frequency: 20.0
    FollowPath:
      plugin: "dwb_core::DWBLocalPlanner"
      max_vel_x: 0.5
      max_vel_y: 0.5
      max_vel_theta: 1.0
      min_vel_x: -0.5
      min_vel_y: -0.5
      min_vel_theta: -1.0
```

**Planner** (global path):
```yaml
planner_server:
  ros__parameters:
    expected_planner_frequency: 20.0
    GridBased:
      plugin: "nav2_navfn_planner/NavfnPlanner"
      tolerance: 0.5
      use_astar: false  # Dijkstra
```

**Behavior Tree Navigator**:
```yaml
bt_navigator:
  ros__parameters:
    global_frame: map
    robot_base_frame: base_link
    odom_topic: /mecanum_drive_controller/odom
    default_bt_xml_filename: "navigate_w_replanning_and_recovery.xml"
```

## Mapping Workflow

### 1. Launch Mapping Mode

**Simulation**:
```bash
# Terminal 1: Gazebo
ros2 launch mecanum_in_gazebo gazebo.launch.py

# Terminal 2: Cartographer
ros2 launch navigation_setup cartographer_mapping.launch.py use_sim:=true

# Terminal 3: Teleop
ros2 run mecanum_in_gazebo mecanum_teleop_key.py
```

**Hardware**:
```bash
# On Raspberry Pi 5 (in Docker)
ros2 launch mecanum_hardware hardware_mapping.launch.py

# On laptop (same network)
export ROS_DOMAIN_ID=42
ros2 run teleop_twist_keyboard teleop_twist_keyboard
rviz2  # Load cartographer.rviz config
```

### 2. Drive and Build Map

- Drive robot around the environment
- Cover all areas you want to map
- Drive slowly for better accuracy
- Close loops (return to starting point) for optimization
- Monitor map quality in RViz

**RViz Setup**:
- Fixed Frame: `map`
- Add Display: `Map` topic `/map`
- Add Display: `LaserScan` topic `/scan`
- Add Display: `RobotModel`
- Add Display: `TF`

### 3. Save Map

```bash
ros2 run nav2_map_server map_saver_cli -f ~/my_map
```

**Output Files**:
- `my_map.pgm` - Map image (grayscale)
- `my_map.yaml` - Map metadata

**Map YAML Example**:
```yaml
image: my_map.pgm
resolution: 0.050000
origin: [-10.000000, -10.000000, 0.000000]
negate: 0
occupied_thresh: 0.65
free_thresh: 0.196
```

### 4. Copy Map to Package

```bash
# On hardware
cp ~/my_map.* /workspace/src/navigation_setup/maps/

# On simulation PC
cp ~/my_map.* ~/002/src/navigation_setup/maps/
```

## Navigation Workflow

### 1. Launch Navigation Mode

**Simulation**:
```bash
# Terminal 1: Gazebo
ros2 launch mecanum_in_gazebo gazebo.launch.py

# Terminal 2: Navigation stack
ros2 launch navigation_setup cartographer_navigation.launch.py \
  use_sim:=true \
  map:=~/002/src/navigation_setup/maps/my_map.yaml
```

**Hardware**:
```bash
# On Raspberry Pi 5
ros2 launch mecanum_hardware hardware_navigation.launch.py \
  map:=/workspace/src/navigation_setup/maps/my_map.yaml
```

### 2. Set Initial Pose (RViz)

1. Open RViz on laptop
2. Click **"2D Pose Estimate"** button (top toolbar)
3. Click on map where robot is located
4. Drag to set orientation
5. AMCL particle cloud should converge around robot

### 3. Send Navigation Goal

**Method 1: RViz**
1. Click **"Nav2 Goal"** button
2. Click destination on map
3. Drag to set goal orientation
4. Robot plans path and navigates autonomously

**Method 2: Command Line**
```bash
ros2 action send_goal /navigate_to_pose nav2_msgs/action/NavigateToPose \
  "{pose: {header: {frame_id: 'map'}, \
   pose: {position: {x: 2.0, y: 1.0, z: 0.0}, \
   orientation: {w: 1.0}}}}"
```

**Method 3: Python Script**
```python
import rclpy
from nav2_simple_commander.robot_navigator import BasicNavigator
from geometry_msgs.msg import PoseStamped

rclpy.init()
navigator = BasicNavigator()

goal_pose = PoseStamped()
goal_pose.header.frame_id = 'map'
goal_pose.pose.position.x = 2.0
goal_pose.pose.position.y = 1.0
goal_pose.pose.orientation.w = 1.0

navigator.goToPose(goal_pose)

while not navigator.isTaskComplete():
    rclpy.spin_once(navigator)

print(navigator.getResult())
```

## Launch Files

### cartographer_mapping.launch.py

**Purpose**: Launch Cartographer for SLAM mapping

**Arguments**:
- `use_sim` (bool): true for simulation, false for hardware
- `resolution` (float): Submap resolution (default: 0.05)
- `publish_period_sec` (float): Submap publish period (default: 1.0)

**Nodes**:
1. `cartographer_node` - SLAM algorithm
2. `cartographer_occupancy_grid_node` - Generates occupancy grid

**Usage**:
```bash
ros2 launch navigation_setup cartographer_mapping.launch.py \
  use_sim:=true \
  resolution:=0.05
```

### cartographer_navigation.launch.py

**Purpose**: Launch navigation with AMCL + Cartographer sensor fusion

**Arguments**:
- `use_sim` (bool): Simulation or hardware
- `map` (string): Path to map YAML file
- `params_file` (string): Nav2 parameters (default: nav2_params.yaml)
- `autostart` (bool): Auto-start Nav2 nodes (default: true)

**Nodes**:
1. `cartographer_node` - Sensor fusion only
2. `map_server` - Serves saved map
3. `amcl` - Monte Carlo localization
4. `controller_server` - Path following
5. `planner_server` - Path planning
6. `recoveries_server` - Recovery behaviors
7. `bt_navigator` - Behavior tree navigation
8. `waypoint_follower` - Waypoint navigation
9. `lifecycle_manager` - Manages node lifecycle

**Usage**:
```bash
ros2 launch navigation_setup cartographer_navigation.launch.py \
  use_sim:=true \
  map:=/path/to/my_map.yaml
```

### nav2_bringup.launch.py

**Purpose**: Launch Nav2 stack only (no Cartographer)

Use when you already have odometry and want just Nav2.

**Usage**:
```bash
ros2 launch navigation_setup nav2_bringup.launch.py \
  map:=/path/to/my_map.yaml \
  params_file:=/path/to/nav2_params.yaml
```

## Topics Reference

### Cartographer Topics

**Subscribed**:
- `/scan` (sensor_msgs/LaserScan) - LiDAR data
- `/odom` (nav_msgs/Odometry) - Wheel odometry
- `/imu/data` (sensor_msgs/Imu) - IMU data

**Published**:
- `/map` (nav_msgs/OccupancyGrid) - SLAM map
- `/submap_list` (cartographer_ros_msgs/SubmapList)
- `/landmark_poses_list` (cartographer_ros_msgs/LandmarkList)
- `/constraint_list` (visualization_msgs/MarkerArray)
- `/trajectory_node_list` (visualization_msgs/MarkerArray)

**Services**:
- `/submap_query` - Query submap
- `/finish_trajectory` - Finish current trajectory
- `/write_state` - Save SLAM state

### Nav2 Topics

**Subscribed**:
- `/map` - Static map from map_server
- `/scan` - Obstacle detection
- `/odom` - Robot odometry

**Published**:
- `/cmd_vel` (geometry_msgs/Twist) - Velocity commands
- `/global_costmap/costmap` - Global planning costmap
- `/local_costmap/costmap` - Local obstacle costmap
- `/plan` (nav_msgs/Path) - Planned path
- `/local_plan` (nav_msgs/Path) - Local trajectory

**Actions**:
- `/navigate_to_pose` - Navigate to goal pose
- `/follow_waypoints` - Follow waypoint list
- `/compute_path_to_pose` - Plan path only (no execution)

### AMCL Topics

**Subscribed**:
- `/scan` - For localization
- `/map` - Static map
- `/initialpose` (geometry_msgs/PoseWithCovarianceStamped) - Initial pose

**Published**:
- `/amcl_pose` (geometry_msgs/PoseWithCovarianceStamped) - Robot pose
- `/particlecloud` (geometry_msgs/PoseArray) - Particle filter cloud

## TF Trees

### Mapping Mode

```
map
 └─ odom (Cartographer)
     └─ base_link (Cartographer)
         ├─ imu_link
         ├─ lidar_link
         ├─ camera_link
         └─ wheel_frames
```

**All TF published by Cartographer**

### Navigation Mode

```
map
 ├─ odom (AMCL)
 │   └─ base_link (Cartographer)
 │       ├─ imu_link
 │       ├─ lidar_link
 │       ├─ camera_link
 │       └─ wheel_frames
 └─ (no direct connection)
```

**TF Publishers**:
- `map → odom`: AMCL (localization on saved map)
- `odom → base_link`: Cartographer (sensor fusion)
- `base_link → sensors`: robot_state_publisher (from URDF)

## Monitoring & Debugging

### Check Navigation Status

```bash
# List Nav2 nodes
ros2 node list | grep -E "(nav2|amcl|map_server|cartographer)"

# Check lifecycle states
ros2 lifecycle list /controller_server
ros2 lifecycle list /planner_server
ros2 lifecycle list /amcl

# Monitor navigation action
ros2 action list
ros2 action info /navigate_to_pose

# Check costmaps
ros2 topic echo /global_costmap/costmap --once
ros2 topic echo /local_costmap/costmap --once

# Monitor AMCL pose
ros2 topic echo /amcl_pose
```

### Check Cartographer

```bash
# Check Cartographer node
ros2 node info /cartographer_node

# Monitor map
ros2 topic hz /map
ros2 topic echo /map --once

# Check TF tree
ros2 run tf2_tools view_frames
evince frames.pdf

# Verify TF publishers
ros2 run tf2_ros tf2_echo map odom      # Should show AMCL
ros2 run tf2_ros tf2_echo odom base_link # Should show Cartographer
```

### Visualize in RViz

**Mapping Config** (`rviz/cartographer.rviz`):
- Fixed Frame: `map`
- Displays: Map, LaserScan, RobotModel, TF, Odometry

**Navigation Config** (`rviz/navigation.rviz`):
- Fixed Frame: `map`
- Displays: Map, LaserScan, RobotModel, TF, Path, ParticleCloud, Costmaps

## Troubleshooting

### Problem: TF_REPEATED_DATA error
**Cause**: Both Cartographer and AMCL publishing `map → odom`  
**Solution**: Use `cartographer_odom.lua` in navigation mode

### Problem: AMCL doesn't converge
**Solutions**:
1. Set better initial pose in RViz
2. Increase AMCL particle count in `amcl_params.yaml`
3. Drive robot around to get more scan matches

### Problem: Robot gets stuck
**Solutions**:
1. Tune DWB controller parameters (velocity limits)
2. Adjust inflation radius in costmap
3. Enable recovery behaviors

### Problem: Poor map quality
**Solutions**:
1. Drive slower during mapping
2. Increase scan matching resolution
3. Close loops (return to starting point)
4. Reduce `imu_gravity_time_constant` for better IMU fusion

### Problem: Path planning fails
**Solutions**:
1. Check global costmap for obstacles
2. Increase planning tolerance
3. Use A* instead of Dijkstra: `use_astar: true`

## Performance Tuning

### For Raspberry Pi 5

**Cartographer**:
```lua
MAP_BUILDER.num_background_threads = 2  # Reduce from 4
POSE_GRAPH.optimize_every_n_nodes = 120  # Increase from 90
```

**Nav2**:
```yaml
controller_server:
  ros__parameters:
    controller_frequency: 10.0  # Reduce from 20.0

planner_server:
  ros__parameters:
    expected_planner_frequency: 10.0  # Reduce from 20.0

global_costmap:
  global_costmap:
    ros__parameters:
      update_frequency: 0.5  # Reduce from 1.0

local_costmap:
  local_costmap:
    ros__parameters:
      update_frequency: 2.0  # Reduce from 5.0
```

## Related Documentation

- [CARTOGRAPHER_CONFIGS.md](../../CARTOGRAPHER_CONFIGS.md) - Cartographer strategy explained
- [mecanum_hardware/README.md](../mecanum_hardware/README.md) - Hardware interface
- [mecanum_in_gazebo/README.md](../mecanum_in_gazebo/README.md) - Simulation
- [ARCHITECTURE.md](../../ARCHITECTURE.md) - System architecture

## Dependencies

**ROS2 Packages**:
- `cartographer_ros`
- `nav2_bringup`
- `nav2_bt_navigator`
- `nav2_controller`
- `nav2_planner`
- `nav2_recoveries`
- `nav2_map_server`
- `nav2_lifecycle_manager`
- `nav2_amcl`
- `nav2_simple_commander` (for Python API)

**System**:
- Adequate CPU for SLAM (RPi5: 2 background threads)
- Network connectivity for wireless RViz

---

**Author**: Mecanum Robot Team  
**Last Updated**: November 2025  
**ROS2 Version**: Humble Hawksbill

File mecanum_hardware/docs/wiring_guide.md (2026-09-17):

# Mecanum Robot Wiring Guide

## Overview
- 4 NEMA23 Stepper Motors (one per wheel)
- 4 Stepper Drivers (DM542T, TB6600, or similar)
- 2 ESP32 Controllers
- 1 Raspberry Pi 5 (16GB)
- 1 LiDAR sensor
- 1 Depth Camera (RealSense D435/D455 or similar)
- 1 IMU sensor

## Motor to ESP Mapping

```
ESP1 (FRONT) - /dev/ttyUSB0
├─ Motor 1 → Front Left Wheel (FL)
└─ Motor 2 → Front Right Wheel (FR)

ESP2 (BACK) - /dev/ttyUSB1
├─ Motor 1 → Back Left Wheel (BL)
└─ Motor 2 → Back Right Wheel (BR)
```

## ESP32 Pin Assignments

### ESP1 (Front Motors)
```
Motor 1 (Front Left):
- GPIO 12 → Driver STEP/PUL
- GPIO 14 → Driver DIR
- GPIO 27 → Driver EN (Enable)

Motor 2 (Front Right):
- GPIO 26 → Driver STEP/PUL
- GPIO 25 → Driver DIR
- GPIO 33 → Driver EN (Enable)
```

### ESP2 (Back Motors)
```
Motor 1 (Back Left):
- GPIO 12 → Driver STEP/PUL
- GPIO 14 → Driver DIR
- GPIO 27 → Driver EN (Enable)

Motor 2 (Back Right):
- GPIO 26 → Driver STEP/PUL
- GPIO 25 → Driver DIR
- GPIO 33 → Driver EN (Enable)
```

## Stepper Driver Configuration

### DIP Switch Settings (example for 1/1 microstepping)
```
DIP1: OFF  DIP2: OFF  DIP3: OFF
Microstep Resolution: Full step (200 steps/rev)
```

Adjust `MICROSTEPS` in firmware accordingly:
- 1/1:  MICROSTEPS = 1
- 1/2:  MICROSTEPS = 2
- 1/4:  MICROSTEPS = 4
- 1/8:  MICROSTEPS = 8
- 1/16: MICROSTEPS = 16

### Current Setting
Set driver current to 80% of motor rated current using potentiometer

## Power Connections

```
24V Power Supply (5A or higher)
├─ Stepper Driver 1 (VCC, GND)
├─ Stepper Driver 2 (VCC, GND)
├─ Stepper Driver 3 (VCC, GND)
└─ Stepper Driver 4 (VCC, GND)

5V Power Supply (3A)
├─ ESP32 #1 (5V, GND via USB or VIN)
└─ ESP32 #2 (5V, GND via USB or VIN)

RPi 5 - USB-C Power (5V 5A)
```

## USB Connection Topology

```
Raspberry Pi 5
├─ USB0 → ESP32 #1 (Front motors)
├─ USB1 → ESP32 #2 (Back motors)
├─ USB2 → LiDAR
├─ USB3 → Depth Camera (RealSense)
└─ USB4 → IMU (or I2C via GPIO)
```

## Identifying USB Ports

```bash
# Before connecting devices
ls /dev/ttyUSB*

# Connect ESP1, check new port
# Connect ESP2, check new port
# Connect LiDAR, check new port

# Create udev rules for persistent naming
sudo nano /etc/udev/rules.d/99-mecanum-robot.rules
```

Add:
```
# ESP32 Controllers
SUBSYSTEM=="tty", ATTRS{idVendor}=="1a86", ATTRS{idProduct}=="7523", SYMLINK+="esp_front"
SUBSYSTEM=="tty", ATTRS{idVendor}=="1a86", ATTRS{idProduct}=="7523", SYMLINK+="esp_back"

# LiDAR
SUBSYSTEM=="tty", ATTRS{idVendor}=="10c4", ATTRS{idProduct}=="ea60", SYMLINK+="lidar"
```

Reload udev:
```bash
sudo udevadm control --reload-rules
sudo udevadm trigger
```

## Safety Considerations

1. **Emergency Stop**: Always have physical E-STOP button
2. **Current Limiting**: Set driver current correctly
3. **Cooling**: Ensure adequate cooling for drivers
4. **Wiring**: Use appropriate gauge wire for motor power
5. **Grounding**: Common ground for all components

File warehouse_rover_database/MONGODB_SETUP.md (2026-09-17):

# Warehouse Rover Database - MongoDB Atlas Setup

## 📚 Overview

This package provides a **MongoDB Atlas** cloud-based database system for the Warehouse Rover, replacing the previous SQLite implementation. It stores QR code detections from warehouse missions in the cloud for easy access and analysis.

---

## 🏗️ Architecture

```
┌─────────────────────────────────────────────────────────┐
│                    MongoDB Atlas Cloud                  │
│  ┌──────────────────┐      ┌──────────────────────┐   │
│  │    missions      │      │     detections        │   │
│  │  - mission_id    │      │  - mission_id         │   │
│  │  - start_time    │      │  - rack_id            │   │
│  │  - end_time      │      │  - shelf_id           │   │
│  │  - status        │      │  - item_code          │   │
│  │  - total_detect  │      │  - confidence         │   │
│  └──────────────────┘      │  - timestamp          │   │
│                            │  - qr_data            │   │
│                            └──────────────────────┘   │
└─────────────────────────────────────────────────────────┘
                              ▲
                              │ pymongo
                              │
              ┌───────────────┴───────────────┐
              │   inventory_node_mongo.py     │
              │   (ROS2 Python Node)          │
              └───────────────┬───────────────┘
                              ▲
                              │ /qr_detections
                              │
              ┌───────────────┴───────────────┐
              │   QR Detection System         │
              │   (Camera + Processing)       │
              └───────────────────────────────┘
```

---

## 🚀 Quick Start

### 1. Create MongoDB Atlas Account (FREE)

1. Go to [MongoDB Atlas](https://www.mongodb.com/cloud/atlas)
2. Sign up for a **FREE** account
3. Create a new cluster (FREE tier M0 is sufficient)
4. Wait for cluster to be created (~5 minutes)

### 2. Get Connection String

1. Click **"Connect"** on your cluster
2. Choose **"Connect your application"**
3. Select **Python** and version **3.6 or later**
4. Copy the connection string:
   ```
   mongodb+srv://<username>:<password>@<cluster>.mongodb.net/
   ```
5. Replace `<password>` with your actual password

### 3. Setup Database Access

1. In Atlas, go to **"Database Access"**
2. Add a database user with username and password
3. In **"Network Access"**, add your IP address (or `0.0.0.0/0` for anywhere - less secure)

### 4. Install Python Dependencies

```bash
# Install pymongo and DNS resolver
pip3 install pymongo dnspython

# Or use requirements file
cd /root/ros2_ws/src/warehouse_rover_database
pip3 install -r requirements.txt
```

### 5. Set Connection String

**Option A: Environment Variable (Recommended)**
```bash
# Add to ~/.bashrc or set before running
export MONGODB_CONNECTION_STRING="mongodb+srv://<username>:<password>@<cluster>.mongodb.net/"
```

**Option B: Edit Config File**
```bash
# Edit config/mongodb_params.yaml
nano /root/ros2_ws/src/warehouse_rover_database/config/mongodb_params.yaml

# Set mongodb_connection_string parameter
```

**Option C: Pass as Launch Argument**
```bash
ros2 launch warehouse_rover_database mongodb_inventory.launch.py \
    mongodb_connection_string:="mongodb+srv://..."
```

### 6. Build and Run

```bash
# Build the package
cd /root/ros2_ws
colcon build --packages-select warehouse_rover_database
source install/setup.bash

# Run the inventory node
ros2 launch warehouse_rover_database mongodb_inventory.launch.py
```

---

## 🧪 Testing

### Test MongoDB Connection (No ROS2)

```bash
cd /root/ros2_ws/src/warehouse_rover_database/warehouse_rover_database

# Set connection string
export MONGODB_CONNECTION_STRING="mongodb+srv://..."

# Run test
python3 mongodb_manager.py
```

Expected output:
```
============================================================
  MongoDB Manager Test
============================================================

✓ Connected to MongoDB: warehouse_rover

1. Starting test mission...
✓ Mission started: TEST_MISSION_001

2. Adding test detections...

3. Getting statistics...
   Total detections: 3
   Average confidence: 0.917
   Unique racks: 2

4. Ending mission...
✓ Mission ended: TEST_MISSION_001 (3 detections)

5. Exporting to JSON...
✓ Exported to: /tmp/test_export.json

6. Getting mission summary...
   Status: completed
   Total detections: 3

✓ MongoDB connection closed
============================================================
✓ All tests passed!
============================================================
```

### Test with Local MongoDB (Optional)

If you don't want to use Atlas, install MongoDB locally:

```bash
# Install MongoDB (Ubuntu)
sudo apt-get update
sudo apt-get install -y mongodb

# Start MongoDB
sudo systemctl start mongodb

# Run with local MongoDB
ros2 launch warehouse_rover_database mongodb_inventory.launch.py use_local:=true
```

---

## 📝 Usage Examples

### Launch with Custom Settings

```bash
# Use Atlas with custom export directory
ros2 launch warehouse_rover_database mongodb_inventory.launch.py \
    export_dir:=/home/rover/mission_exports

# Use local MongoDB
ros2 launch warehouse_rover_database mongodb_inventory.launch.py \
    use_local:=true
```

### Monitor Topics

```bash
# View QR detections being received
ros2 topic echo /qr_detections

# Check node status
ros2 node info /inventory_node
```

### Access Data from MongoDB Atlas

1. Go to your Atlas cluster
2. Click **"Browse Collections"**
3. View data in:
   - `warehouse_rover.missions` - Mission records
   - `warehouse_rover.detections` - QR detection data

### Export Mission Data

```bash
# Exports are automatically created on node shutdown in:
/tmp/inventory_exports/MISSION_<timestamp>.json

# View exported JSON
cat /tmp/inventory_exports/MISSION_*.json | jq
```

---

## 🔧 Configuration

### Parameters (`config/mongodb_params.yaml`)

| Parameter | Default | Description |
|---|---|---|
| `mongodb_connection_string` | `""` | MongoDB Atlas URI |
| `database_name` | `warehouse_rover` | Database name |
| `auto_export` | `true` | Export on shutdown |
| `export_dir` | `/tmp/inventory_exports` | Export directory |
| `use_local_mongodb` | `false` | Use local MongoDB |

---

## 📊 Data Schema

### Missions Collection

```json
{
  "mission_id": "MISSION_20251207_143052",
  "start_time": "2025-12-07T14:30:52.123Z",
  "end_time": "2025-12-07T15:45:30.456Z",
  "status": "completed",
  "total_detections": 42,
  "metadata": {
    "created_by": "warehouse_rover",
    "version": "1.0"
  }
}
```

### Detections Collection

```json
{
  "mission_id": "MISSION_20251207_143052",
  "rack_id": "R01",
  "shelf_id": "S2",
  "item_code": "ITEM12345",
  "qr_data": "R01-S2-ITEM12345",
  "confidence": 0.95,
  "timestamp": "2025-12-07T14:35:12.789Z",
  "metadata": {
    "center_x": 320.5,
    "center_y": 240.8,
    "size_pixels": 150,
    "processing_time_ms": 45.2,
    "camera_height": 1.2
  }
}
```

---

## 🔒 Security Best Practices

1. **Never commit connection strings** to Git
2. Use environment variables for credentials
3. Create **read-only users** for analytics
4. Set **IP whitelist** in Atlas Network Access
5. Enable **encryption at rest** (free in Atlas)
6. Use **strong passwords** for database users

---

## 🐛 Troubleshooting

### Connection Errors

```bash
# Test DNS resolution
ping <your-cluster>.mongodb.net

# Check firewall
sudo ufw status
```

### Import Errors

```bash
# Verify pymongo installation
python3 -c "import pymongo; print(pymongo.__version__)"

# Reinstall if needed
pip3 install --upgrade pymongo dnspython
```

### Permission Errors

```bash
# Check export directory permissions
ls -la /tmp/inventory_exports
sudo chmod 777 /tmp/inventory_exports
```

---

## 📈 Querying Data

### Using MongoDB Compass (GUI)

1. Download [MongoDB Compass](https://www.mongodb.com/products/compass)
2. Connect using your connection string
3. Browse collections visually

### Using Python

```python
from warehouse_rover_database.mongodb_manager import MongoDBManager

db = MongoDBManager()

# Get mission summary
summary = db.get_mission_summary("MISSION_20251207_143052")

# Get all detections for a rack
detections = db.get_detections_by_rack("R01")

# Get statistics
stats = db.get_statistics()
print(f"Total detections: {stats['total_detections']}")
```

---

## 🔄 Migration from SQLite

If you have existing SQLite data:

```bash
# Export from SQLite
sqlite3 /tmp/warehouse_inventory.db ".dump" > backup.sql

# Parse and import to MongoDB (script not provided, manual process)
# Or start fresh with new missions
```

---

## 🎯 Next Steps

1. ✅ Setup MongoDB Atlas
2. ✅ Configure connection string
3. ✅ Test connection
4. ✅ Run inventory node
5. ✅ Integrate with QR detection
6. ✅ View data in Atlas dashboard
7. ✅ Create analytics queries

---

## 📞 Support

For issues:
- Check Atlas dashboard for cluster status
- Review ROS2 logs: `ros2 node info /inventory_node`
- Test connection: `python3 mongodb_manager.py`

---

**Made with ❤️ for Warehouse Automation**

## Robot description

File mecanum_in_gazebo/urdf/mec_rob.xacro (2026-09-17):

<?xml version="1.0" ?>
<robot name="mec_rob" xmlns:xacro="http://www.ros.org/wiki/xacro">

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
<xacro:arg name="use_sim" default="true"/>
<xacro:arg name="esp1_port" default="/dev/esp_front"/>
<xacro:arg name="esp2_port" default="/dev/esp_back"/>
<xacro:arg name="use_depth_camera" default="false"/>

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
<xacro:include filename="$(find mecanum_in_gazebo)/urdf/mec_rob.ros2_control.hardware.xacro"/>

<xacro:include filename="lidar.xacro" />
<xacro:include filename="lidar.gazebo" />
<xacro:include filename="depth_camera.xacro" />
<xacro:include filename="depth_camera.gazebo" />
<xacro:include filename="materials.xacro" />
<xacro:include filename="mec_rob.trans" />
<xacro:include filename="mec_rob.gazebo" />
<xacro:include filename="imu.gazebo" />
<xacro:include filename="imu.xacro" />


<link name="base_link">
  <inertial>
    <origin xyz="6.760415092149816e-05 -2.9513096198865094e-17 2.0788276408363705e-05" rpy="0 0 0"/>
    <mass value="19.3528550466136"/>
    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
  </inertial>
  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
</link>

<link name="wheel_frame_FL_1">
  <inertial>
    <origin xyz="-2.1897287448918723e-05 -0.023738528231967565 3.1378817485983033e-06" rpy="0 0 0"/>
    <mass value="0.30282113324994747"/>
    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
  </inertial>
  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
</link>

<link name="roller_14_1">
  <inertial>
    <origin xyz="-0.01730009422242043 -0.01664777121912278 -2.6367796834847468e-15" rpy="0 0 0"/>
    <mass value="0.014233736590697255"/>
    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
  </inertial>
  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
</link>

<link name="roller_16_1">
  <inertial>
    <origin xyz="-0.01325231160541368 -0.01664777187914801 0.011119554128877593" rpy="0 0 0"/>
    <mass value="0.01423373659069693"/>
    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
  </inertial>
  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
</link>

<link name="roller_13_1">
  <inertial>
    <origin xyz="-0.0030044941161637972 -0.016647462795977563 0.01703683072301009" rpy="0 0 0"/>
    <mass value="0.014233736590696914"/>
    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
  </inertial>
  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
</link>

<link name="roller_12_1">
  <inertial>
    <origin xyz="0.008650090286065698 -0.016647462135951696 0.01498198481151108" rpy="0 0 0"/>
    <mass value="0.01423373659069688"/>
    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
  </inertial>
  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
</link>

<link name="roller_15_1">
  <inertial>
    <origin xyz="0.016255980142600823 -0.016647462135952473 0.005916818201972901" rpy="0 0 0"/>
    <mass value="0.014233736590697089"/>
    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
  </inertial>
  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
</link>

<link name="roller_17_1">
  <inertial>
    <origin xyz="0.01625636867654784 -0.016647462135950142 -0.005917227864846754" rpy="0 0 0"/>
    <mass value="0.014233736590697006"/>
    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
  </inertial>
  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
</link>

<link name="roller_18_1">
  <inertial>
    <origin xyz="0.008650058329703877 -0.016647462793830475 -0.014981985403539554" rpy="0 0 0"/>
    <mass value="0.01423373659069696"/>
    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
  </inertial>
  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
</link>

<link name="roller_10_1">
  <inertial>
    <origin xyz="-0.0030041143571402362 -0.016647462795977036 -0.017036976509655844" rpy="0 0 0"/>
    <mass value="0.014233736590696993"/>
    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
  </inertial>
  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
</link>

<link name="roller_11_1">
  <inertial>
    <origin xyz="-0.013251875204888214 -0.016647462795978424 -0.011119602623583382" rpy="0 0 0"/>
    <mass value="0.014233736590697477"/>
    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
  </inertial>
  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
</link>

<link name="wheel_frame_FR_1">
  <inertial>
    <origin xyz="-2.1897287449737513e-05 0.02375019110552612 3.1378817487137666e-06" rpy="0 0 0"/>
    <mass value="0.30282113324994836"/>
    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
  </inertial>
  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
</link>

<link name="roller_7_1">
  <inertial>
    <origin xyz="0.017300094908289848 -0.01664777187914701 -1.2073675392798577e-15" rpy="0 0 0"/>
    <mass value="0.014233736590697038"/>
    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
  </inertial>
  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
</link>

<link name="roller_5_1">
  <inertial>
    <origin xyz="0.013252319854933331 -0.016647771219124002 -0.011119998238488766" rpy="0 0 0"/>
    <mass value="0.01423373659069685"/>
    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
  </inertial>
  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
</link>

<link name="roller_3_1">
  <inertial>
    <origin xyz="0.00300454811119516 -0.01664777121912328 -0.017036408760246494" rpy="0 0 0"/>
    <mass value="0.014233736590696551"/>
    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
  </inertial>
  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
</link>

<link name="roller_6_1">
  <inertial>
    <origin xyz="-0.008650030959834937 -0.016647771219122087 -0.0149822251925512" rpy="0 0 0"/>
    <mass value="0.014233736590697"/>
    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
  </inertial>
  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
</link>

<link name="roller_8_1">
  <inertial>
    <origin xyz="-0.01625624772515452 -0.016647771219123614 -0.005917264735106481" rpy="0 0 0"/>
    <mass value="0.01423373659069701"/>
    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
  </inertial>
  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
</link>

<link name="roller_9_1">
  <inertial>
    <origin xyz="-0.01625685983158369 -0.01664777188086597 0.005916855307413364" rpy="0 0 0"/>
    <mass value="0.014233736590696988"/>
    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
  </inertial>
  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
</link>

<link name="roller_4_1">
  <inertial>
    <origin xyz="-0.008650063605525643 -0.016647771879150397 0.014982225786529486" rpy="0 0 0"/>
    <mass value="0.01423373659069714"/>
    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
  </inertial>
  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
</link>

<link name="roller_1_1">
  <inertial>
    <origin xyz="0.003003927989318908 -0.01664777187914948 0.017037263649050942" rpy="0 0 0"/>
    <mass value="0.014233736590697087"/>
    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
  </inertial>
  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
</link>

<link name="roller_2_1">
  <inertial>
    <origin xyz="0.013252311605417427 -0.016647771879147594 0.011119554128875348" rpy="0 0 0"/>
    <mass value="0.014233736590697151"/>
    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
  </inertial>
  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
</link>

<link name="wheel_frame_BL_1">
  <inertial>
    <origin xyz="3.1733464467276207e-10 -0.023749808894473867 -7.519251293838056e-14" rpy="0 0 0"/>
    <mass value="0.30282113324994536"/>
    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
  </inertial>
  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
</link>

<link name="roller_23_1">
  <inertial>
    <origin xyz="0.017300094222420792 -0.016647771219122837 2.5049406993105094e-15" rpy="0 0 0"/>
    <mass value="0.014233736590696983"/>
    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
  </inertial>
  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
</link>

<link name="roller_22_1">
  <inertial>
    <origin xyz="0.013252320380338786 -0.016647771879150813 -0.011119998679360706" rpy="0 0 0"/>
    <mass value="0.014233736590697042"/>
    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
  </inertial>
  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
</link>

<link name="roller_25_1">
  <inertial>
    <origin xyz="0.003004548230298998 -0.016647771879146955 -0.01703640943569361" rpy="0 0 0"/>
    <mass value="0.014233736590697047"/>
    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
  </inertial>
  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
</link>

<link name="roller_21_1">
  <inertial>
    <origin xyz="-0.008650030959835658 -0.016647771219122615 -0.014982225192550146" rpy="0 0 0"/>
    <mass value="0.014233736590696936"/>
    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
  </inertial>
  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
</link>

<link name="roller_26_1">
  <inertial>
    <origin xyz="-0.016256248369660345 -0.016647771879147844 -0.005917264969692589" rpy="0 0 0"/>
    <mass value="0.014233736590697033"/>
    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
  </inertial>
  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
</link>

<link name="roller_27_1">
  <inertial>
    <origin xyz="-0.01625685918905319 -0.016647771222854157 0.005916855073576734" rpy="0 0 0"/>
    <mass value="0.014233736590697002"/>
    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
  </inertial>
  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
</link>

<link name="roller_20_1">
  <inertial>
    <origin xyz="-0.008650063605519703 -0.016647771879149093 0.01498222578652882" rpy="0 0 0"/>
    <mass value="0.014233736590696985"/>
    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
  </inertial>
  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
</link>

<link name="roller_19_1">
  <inertial>
    <origin xyz="0.0030039278702186645 -0.01664777121912278 0.017037262973597655" rpy="0 0 0"/>
    <mass value="0.014233736590697066"/>
    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
  </inertial>
  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
</link>

<link name="roller_24_1">
  <inertial>
    <origin xyz="0.0132523116054169 -0.016647771879146317 0.011119554128877464" rpy="0 0 0"/>
    <mass value="0.014233736590697"/>
    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
  </inertial>
  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
</link>

<link name="wheel_frame_BR_1">
  <inertial>
    <origin xyz="3.1733479732842795e-10 0.023761471768032644 -7.514689871510898e-14" rpy="0 0 0"/>
    <mass value="0.30282113324994864"/>
    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
  </inertial>
  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
</link>

<link name="roller_34_1">
  <inertial>
    <origin xyz="-0.01730009422242071 -0.016647771219125196 -1.0685896612017132e-15" rpy="0 0 0"/>
    <mass value="0.014233736590696927"/>
    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
  </inertial>
  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
</link>

<link name="roller_30_1">
  <inertial>
    <origin xyz="-0.013252311605417719 -0.016647771879147177 0.011119554128875175" rpy="0 0 0"/>
    <mass value="0.014233736590697087"/>
    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
  </inertial>
  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
</link>
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

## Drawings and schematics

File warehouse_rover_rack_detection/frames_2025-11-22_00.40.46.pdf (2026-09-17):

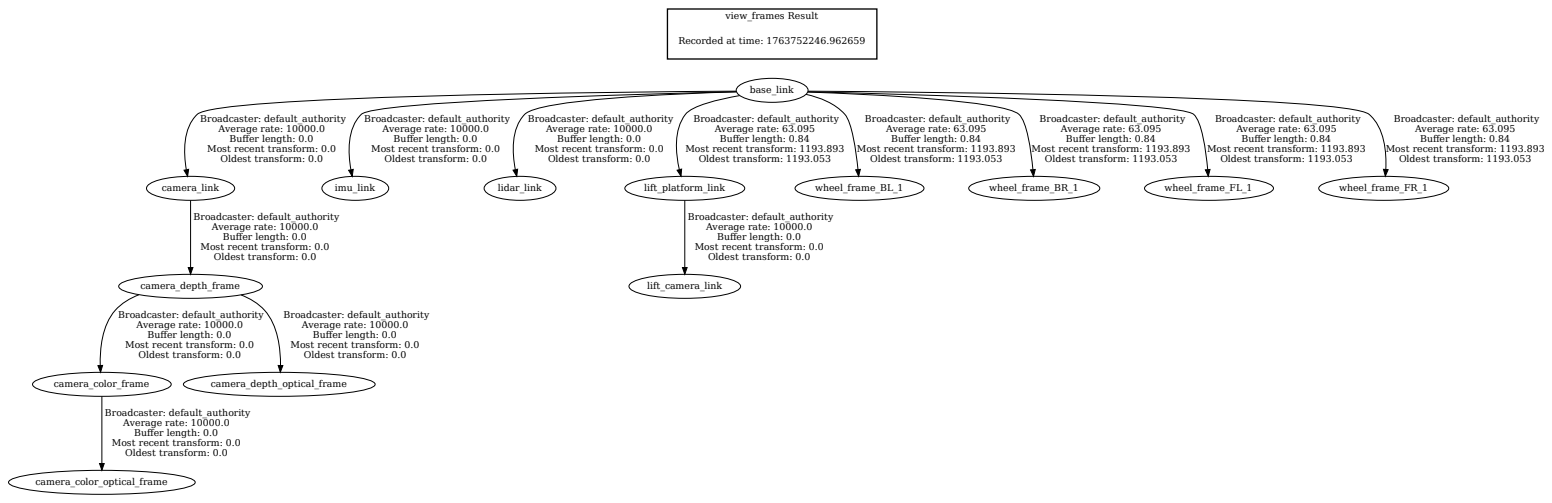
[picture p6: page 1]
view_frames Result; camera_depth_frame; camera_color_frame; camera_depth_optical_frame; camera_color_optical_frame; camera_link; base_link; imu_link; lidar_link; lift_platform_link; Broadcaster: default_authority Average rate: 63.095 Buffer length: 0.84; Oldest transform: 1193.053; wheel_frame_BL_1; wheel_frame_BR_1; wheel_frame_FL_1; wheel_frame_FR_1; lift_camera_link

Recorded at time: 1763752246.962659

Broadcaster: default_authority
Average rate: 10000.0
Buffer length: 0.0
Most recent transform: 0.0
Oldest transform: 0.0

Most recent transform: 1193.893

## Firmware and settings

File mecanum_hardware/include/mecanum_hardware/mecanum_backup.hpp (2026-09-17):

// Copyright 2024 Mecanum Hardware
//
// Licensed under the Apache License, Version 2.0 (the "License");
// you may not use this file except in compliance with the License.
// You may obtain a copy of the License at
//
//     http://www.apache.org/licenses/LICENSE-2.0
//
// Unless required by applicable law or agreed to in writing, software
// distributed under the License is distributed on an "AS IS" BASIS,
// WITHOUT WARRANTIES OR CONDITIONS OF ANY KIND, either express or implied.
// See the License for the specific language governing permissions and
// limitations under the License.

#ifndef MECANUM_HARDWARE__MECANUM_STEPPER_INTERFACE_HPP_
#define MECANUM_HARDWARE__MECANUM_STEPPER_INTERFACE_HPP_

#include <memory>
#include <string>
#include <vector>
#include <chrono>

#include "hardware_interface/handle.hpp"
#include "hardware_interface/hardware_info.hpp"
#include "hardware_interface/system_interface.hpp"
#include "hardware_interface/types/hardware_interface_return_values.hpp"
#include "rclcpp/macros.hpp"
#include "rclcpp_lifecycle/node_interfaces/lifecycle_node_interface.hpp"
#include "rclcpp_lifecycle/state.hpp"
#include "rclcpp/rclcpp.hpp"
#include "sensor_msgs/msg/imu.hpp"

namespace mecanum_hardware
{

/// \brief ESP32 connection structure
struct ESPConnection
{
  std::string port;              // Serial port (e.g., /dev/ttyUSB0)
  int baudrate;                  // Baudrate (default: 115200)
  int fd;                        // File descriptor for serial port
  std::vector<int> motor_indices; // Motor indices controlled by this ESP (0=FL, 1=FR, 2=BL, 3=BR)
  
  ESPConnection() : baudrate(115200), fd(-1) {}
};

/// \brief Hardware interface for mecanum robot with NEMA23 stepper motors
///
/// This hardware interface communicates with two ESP32 microcontrollers
/// to control 4 NEMA23 stepper motors (no encoders) for a mecanum drive robot.
/// 
/// Hardware configuration:
/// - ESP1: Controls front-left and front-right motors via stepper drivers
/// - ESP2: Controls back-left and back-right motors via stepper drivers
/// - IMU: Connected to Raspberry Pi 5 via GPIO (optional, for sensor fusion)
/// - LiDAR: RPLidar A1 connected via USB to Raspberry Pi 5
/// - Depth Camera: RealSense D435/D455 (optional)
///
/// Communication protocol with ESP32:
/// - Command format: "V,steps_per_sec_motor1,steps_per_sec_motor2\n"
/// - Example: "V,100.0,-50.5\n" (motor1 forward @ 100 steps/s, motor2 backward @ 50.5 steps/s)
///
/// TF tree during operation:
/// - Mapping: odom -> base_link (published by cartographer using IMU + wheel odometry)
/// - Navigation: map -> odom (AMCL), odom -> base_link (cartographer with sensor fusion)
///
class MecanumStepperInterface : public hardware_interface::SystemInterface
{
public:
  RCLCPP_SHARED_PTR_DEFINITIONS(MecanumStepperInterface)

  /// \brief Initialize the hardware interface
  hardware_interface::CallbackReturn on_init(
    const hardware_interface::HardwareInfo & info) override;

  /// \brief Configure the hardware interface (open serial ports, setup IMU subscriber)
  hardware_interface::CallbackReturn on_configure(
    const rclcpp_lifecycle::State & previous_state) override;

  /// \brief Cleanup the hardware interface
  hardware_interface::CallbackReturn on_cleanup(
    const rclcpp_lifecycle::State & previous_state) override;

  /// \brief Export state interfaces (position, velocity for each wheel)
  std::vector<hardware_interface::StateInterface> export_state_interfaces() override;

  /// \brief Export command interfaces (velocity for each wheel)
  std::vector<hardware_interface::CommandInterface> export_command_interfaces() override;

  /// \brief Activate the hardware (zero motors, prepare for operation)
  hardware_interface::CallbackReturn on_activate(
    const rclcpp_lifecycle::State & previous_state) override;

  /// \brief Deactivate the hardware (stop motors, close serial ports)
  hardware_interface::CallbackReturn on_deactivate(
    const rclcpp_lifecycle::State & previous_state) override;

  /// \brief Read sensor data and calculate odometry
  hardware_interface::return_type read(
    const rclcpp::Time & time, const rclcpp::Duration & period) override;

  /// \brief Write velocity commands to motors
  hardware_interface::return_type write(
    const rclcpp::Time & time, const rclcpp::Duration & period) override;

private:
  // ========== ESP32 Serial Communication ==========
  
  /// \brief Open serial port to ESP32
  /// \param esp ESP connection structure
  /// \return true if successful, false otherwise
  bool open_esp_port(ESPConnection& esp);
  
  /// \brief Close serial port to ESP32
  /// \param esp ESP connection structure
  void close_esp_port(ESPConnection& esp);
  
  /// \brief Send velocity command to ESP32
  /// \param esp ESP connection structure
  /// \param velocities Vector of velocities (rad/s) for motors controlled by this ESP
  /// \return true if successful, false otherwise
  bool send_velocity_command(ESPConnection& esp, const std::vector<double>& velocities);
  
  /// \brief Read feedback from ESP32 (if available)
  /// \param esp ESP connection structure
  /// \param buffer Buffer to store received data
  /// \param max_bytes Maximum bytes to read
  /// \return Number of bytes read
  ssize_t read_esp_feedback(ESPConnection& esp, char* buffer, size_t max_bytes);
  
  // ========== Odometry Calculation ==========
  
  /// \brief Calculate odometry from wheel velocities and IMU data
  /// \param period Time period since last update
  void calculate_odometry(const rclcpp::Duration & period);
  
  /// \brief Convert angular velocity (rad/s) to steps per second
  /// \param rad_per_sec Angular velocity in rad/s
  /// \return Steps per second
  double velocity_to_steps_per_sec(double rad_per_sec);
  
  // ========== Hardware Parameters ==========
  
  // Stepper motor parameters (NEMA23)
  double steps_per_revolution_;  // Typically 200 for 1.8° step angle
  double wheel_radius_;          // Wheel radius in meters (e.g., 0.05m = 5cm)
  double gear_ratio_;            // Gear ratio (1.0 = direct drive)
  
  // Robot dimensions (loaded from URDF or config)
  double wheel_separation_x_;    // Front-back wheel separation (m)
  double wheel_separation_y_;    // Left-right wheel separation (m)
  
  // IMU fusion
  bool use_imu_;                 // Enable IMU fusion for better odometry
  double imu_angular_velocity_z_; // Latest IMU angular velocity (yaw rate)
  
  // ========== ESP32 Connections ==========
  
  std::vector<ESPConnection> esp_connections_;  // Two ESP32 controllers
  
  // ========== Wheel State ==========
  
  std::vector<std::string> wheel_names_;        // Wheel joint names
  std::vector<double> hw_commands_velocity_;    // Commanded velocities (rad/s)
  std::vector<double> hw_states_position_;      // Wheel positions (rad)
  std::vector<double> hw_states_velocity_;      // Wheel velocities (rad/s)
  
  // ========== ROS2 Node for IMU Subscription ==========
  
  rclcpp::Node::SharedPtr node_;                // ROS2 node for IMU subscription
  rclcpp::Subscription<sensor_msgs::msg::Imu>::SharedPtr imu_subscriber_;
  
  // ========== Timing and Throttling ==========
  
  rclcpp::Time last_read_time_;                 // Last time read() was called
  bool first_read_;                             // Flag for first read
  
  // Clock for RCLCPP macros (STEADY_TIME)
  rclcpp::Clock::SharedPtr steady_clock_;
  
  // Manual throttling using std::chrono (more reliable than RCLCPP_*_THROTTLE in hardware interface)
  std::chrono::steady_clock::time_point last_slip_warning_time_;
  std::chrono::steady_clock::time_point last_write_warning_time_;
};

}  // namespace mecanum_hardware

#endif  // MECANUM_HARDWARE__MECANUM_STEPPER_INTERFACE_HPP_

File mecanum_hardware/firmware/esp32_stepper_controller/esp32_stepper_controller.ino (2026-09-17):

/*
 * ESP32 Stepper Motor Controller for Mecanum Robot
 * Controls 2 NEMA23 stepper motors via drivers (one per wheel)
 * Communication: Serial @ 115200 baud
 * Protocol: "V,steps_per_sec_motor1,steps_per_sec_motor2\n"
 * 
 * Hardware Setup:
 * - ESP1 (Front): Controls Front Left (FL) + Front Right (FR) wheels
 * - ESP2 (Back):  Controls Back Left (BL) + Back Right (BR) wheels
 * 
 * Each motor connects to a separate stepper driver
 */

// ========== CONFIGURATION - MODIFY FOR YOUR WIRING ==========

// Set ESP ID: 1 for FRONT ESP, 2 for BACK ESP
const int ESP_ID = 1;  // ⚠️ CHANGE TO 2 FOR BACK ESP

// Motor 1 pins (Front Left or Back Left wheel)
const int MOTOR1_STEP_PIN = 12;
const int MOTOR1_DIR_PIN = 14;
const int MOTOR1_ENABLE_PIN = 27;

// Motor 2 pins (Front Right or Back Right wheel)
const int MOTOR2_STEP_PIN = 26;
const int MOTOR2_DIR_PIN = 25;
const int MOTOR2_ENABLE_PIN = 33;

// Stepper driver configuration
const int MICROSTEPS = 1;  // Set according to your driver DIP switches (1, 2, 4, 8, 16, 32)
const int STEPS_PER_REV = 200 * MICROSTEPS;  // NEMA23 = 200 steps/rev (1.8°)

// Motor control parameters
const float MAX_ACCEL = 2000.0;  // steps/sec² (adjust for smooth acceleration)
const float MAX_SPEED = 3000.0;  // steps/sec (safety limit)

// ================================================================

// Motor state structure
struct Motor {
  int step_pin;
  int dir_pin;
  int enable_pin;
  float target_steps_per_sec;
  float current_steps_per_sec;
  unsigned long last_step_time;
  unsigned long step_interval_us;
  bool direction;  // true = forward, false = backward
  const char* name;
};

Motor motor1, motor2;

// Control loop timing
const float CONTROL_FREQ = 100.0;  // Hz
const unsigned long CONTROL_PERIOD_US = 1000000.0 / CONTROL_FREQ;
unsigned long last_control_time = 0;

// Serial communication
String inputString = "";
boolean stringComplete = false;

// Watchdog timer (stops motors if no command received)
unsigned long last_command_time = 0;
const unsigned long WATCHDOG_TIMEOUT = 500;  // ms

// Statistics
unsigned long loop_count = 0;
unsigned long last_stats_time = 0;

void setup() {
  Serial.begin(115200);
  Serial.setTimeout(10);
  
  // Initialize Motor 1
  motor1.step_pin = MOTOR1_STEP_PIN;
  motor1.dir_pin = MOTOR1_DIR_PIN;
  motor1.enable_pin = MOTOR1_ENABLE_PIN;
  motor1.target_steps_per_sec = 0.0;
  motor1.current_steps_per_sec = 0.0;
  motor1.last_step_time = 0;
  motor1.step_interval_us = 0;
  motor1.direction = true;
  motor1.name = (ESP_ID == 1) ? "FL" : "BL";
  
  pinMode(motor1.step_pin, OUTPUT);
  pinMode(motor1.dir_pin, OUTPUT);
  pinMode(motor1.enable_pin, OUTPUT);
  digitalWrite(motor1.enable_pin, LOW);  // Enable motor (active LOW)
  digitalWrite(motor1.step_pin, LOW);
  digitalWrite(motor1.dir_pin, LOW);
  
  // Initialize Motor 2
  motor2.step_pin = MOTOR2_STEP_PIN;
  motor2.dir_pin = MOTOR2_DIR_PIN;
  motor2.enable_pin = MOTOR2_ENABLE_PIN;
  motor2.target_steps_per_sec = 0.0;
  motor2.current_steps_per_sec = 0.0;
  motor2.last_step_time = 0;
  motor2.step_interval_us = 0;
  motor2.direction = true;
  motor2.name = (ESP_ID == 1) ? "FR" : "BR";
  
  pinMode(motor2.step_pin, OUTPUT);
  pinMode(motor2.dir_pin, OUTPUT);
  pinMode(motor2.enable_pin, OUTPUT);
  digitalWrite(motor2.enable_pin, LOW);  // Enable motor (active LOW)
  digitalWrite(motor2.step_pin, LOW);
  digitalWrite(motor2.dir_pin, LOW);
  
  inputString.reserve(100);
  
  // Startup message
  Serial.println("\n========================================");
  Serial.println("ESP32 Mecanum Stepper Controller");
  Serial.print("ESP_ID: ");
  Serial.println(ESP_ID);
  Serial.print("Position: ");
  Serial.println((ESP_ID == 1) ? "FRONT (FL + FR)" : "BACK (BL + BR)");
  Serial.print("Motor 1 (");
  Serial.print(motor1.name);
  Serial.print("): STEP=");
  Serial.print(MOTOR1_STEP_PIN);
  Serial.print(" DIR=");
  Serial.print(MOTOR1_DIR_PIN);
  Serial.print(" EN=");
  Serial.println(MOTOR1_ENABLE_PIN);
  Serial.print("Motor 2 (");
  Serial.print(motor2.name);
  Serial.print("): STEP=");
  Serial.print(MOTOR2_STEP_PIN);
  Serial.print(" DIR=");
  Serial.print(MOTOR2_DIR_PIN);
  Serial.print(" EN=");
  Serial.println(MOTOR2_ENABLE_PIN);
  Serial.print("Microsteps: ");
  Serial.println(MICROSTEPS);
  Serial.print("Steps/Rev: ");
  Serial.println(STEPS_PER_REV);
  Serial.println("Protocol: V,steps_per_sec_m1,steps_per_sec_m2");
  Serial.println("Ready!");
  Serial.println("========================================\n");
  
  last_command_time = millis();
  last_stats_time = millis();
}

void loop() {
  unsigned long current_time = micros();
  loop_count++;
  
  // Read serial commands
  if (Serial.available()) {
    char inChar = (char)Serial.read();
    if (inChar == '\n') {
      stringComplete = true;
    } else {
      inputString += inChar;
    }
  }
  
  // Process command
  if (stringComplete) {
    parseCommand(inputString);
    inputString = "";
    stringComplete = false;
    last_command_time = millis();
  }
  
  // Watchdog: stop motors if no command received
  if (millis() - last_command_time > WATCHDOG_TIMEOUT) {
    if (motor1.target_steps_per_sec != 0.0 || motor2.target_steps_per_sec != 0.0) {
      motor1.target_steps_per_sec = 0.0;
      motor2.target_steps_per_sec = 0.0;
      Serial.println("WATCHDOG: Motors stopped (no command)");
    }
  }
  
  // Control loop - update velocities with acceleration limiting
  if (current_time - last_control_time >= CONTROL_PERIOD_US) {
    updateMotorVelocity(motor1);
    updateMotorVelocity(motor2);
    last_control_time = current_time;
  }
  
  // Step motors
  stepMotor(motor1, current_time);
  stepMotor(motor2, current_time);
  
  // Print statistics every 5 seconds
  if (millis() - last_stats_time > 5000) {
    printStats();
    last_stats_time = millis();
  }
}

void parseCommand(String cmd) {
  // Expected format: "V,steps_per_sec_m1,steps_per_sec_m2"
  if (cmd.startsWith("V,")) {
    cmd = cmd.substring(2);  // Remove "V,"
    
    int commaIndex = cmd.indexOf(',');
    if (commaIndex > 0) {
      String m1_str = cmd.substring(0, commaIndex);
      String m2_str = cmd.substring(commaIndex + 1);
      
      float m1_speed = m1_str.toFloat();
      float m2_speed = m2_str.toFloat();
      
      // Apply speed limits
      motor1.target_steps_per_sec = constrain(m1_speed, -MAX_SPEED, MAX_SPEED);
      motor2.target_steps_per_sec = constrain(m2_speed, -MAX_SPEED, MAX_SPEED);
      
      // Optional: Echo command for debugging
      // Serial.print("CMD: ");
      // Serial.print(motor1.name);
      // Serial.print("=");
      // Serial.print(motor1.target_steps_per_sec);
      // Serial.print(" ");
      // Serial.print(motor2.name);
      // Serial.print("=");
      // Serial.println(motor2.target_steps_per_sec);
    }
  } else if (cmd.startsWith("STATUS")) {
    printStatus();
  } else if (cmd.startsWith("STOP")) {
    motor1.target_steps_per_sec = 0.0;
    motor2.target_steps_per_sec = 0.0;
    Serial.println("EMERGENCY STOP");
  }
}

void updateMotorVelocity(Motor &motor) {
  float error = motor.target_steps_per_sec - motor.current_steps_per_sec;
  float max_change = MAX_ACCEL / CONTROL_FREQ;
  
  // Apply acceleration limiting
  if (abs(error) > max_change) {
    motor.current_steps_per_sec += (error > 0) ? max_change : -max_change;
  } else {
    motor.current_steps_per_sec = motor.target_steps_per_sec;
  }
  
  // Update direction pin
  if (motor.current_steps_per_sec >= 0) {
    motor.direction = true;
    digitalWrite(motor.dir_pin, HIGH);
  } else {
    motor.direction = false;
    digitalWrite(motor.dir_pin, LOW);
  }
  
  // Calculate step interval (microseconds between steps)
  float abs_speed = abs(motor.current_steps_per_sec);
  if (abs_speed > 0.1) {
    motor.step_interval_us = 1000000.0 / abs_speed;
  } else {
    motor.step_interval_us = 0;  // Motor stopped
  }
}

void stepMotor(Motor &motor, unsigned long current_time) {
  if (motor.step_interval_us == 0) {
    return;  // Motor stopped
  }
  
  if (current_time - motor.last_step_time >= motor.step_interval_us) {
    // Generate step pulse
    digitalWrite(motor.step_pin, HIGH);
    delayMicroseconds(2);  // Minimum pulse width (check your driver datasheet)
    digitalWrite(motor.step_pin, LOW);
    
    motor.last_step_time = current_time;
  }
}

void printStatus() {
  Serial.println("\n--- STATUS ---");
  Serial.print("ESP_ID: ");
  Serial.println(ESP_ID);
  Serial.print(motor1.name);
  Serial.print(": target=");
  Serial.print(motor1.target_steps_per_sec);
  Serial.print(" current=");
  Serial.print(motor1.current_steps_per_sec);
  Serial.print(" dir=");
  Serial.println(motor1.direction ? "FWD" : "REV");
  Serial.print(motor2.name);
  Serial.print(": target=");
  Serial.print(motor2.target_steps_per_sec);
  Serial.print(" current=");
  Serial.print(motor2.current_steps_per_sec);
  Serial.print(" dir=");
  Serial.println(motor2.direction ? "FWD" : "REV");
  Serial.println("-------------\n");
}

void printStats() {
  Serial.print("STATS: ESP");
  Serial.print(ESP_ID);
  Serial.print(" | ");
  Serial.print(motor1.name);
  Serial.print("=");
  Serial.print(motor1.current_steps_per_sec, 1);
  Serial.print(" ");
  Serial.print(motor2.name);
  Serial.print("=");
  Serial.print(motor2.current_steps_per_sec, 1);
  Serial.print(" | Loops/sec=");
  Serial.println(loop_count / 5);
  loop_count = 0;
}

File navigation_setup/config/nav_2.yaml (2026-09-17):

# Nav2 Configuration - DOORWAY NAVIGATION TUNED
# Robot: 47cm width × 66cm length, Mecanum drive
# Target: 90cm doorways with smooth curved paths

amcl:
  ros__parameters:
    use_sim_time: False
    alpha1: 0.2
    alpha2: 0.2
    alpha3: 0.2
    alpha4: 0.2
    alpha5: 0.2
    base_frame_id: "base_link"
    beam_skip_distance: 0.5
    beam_skip_error_threshold: 0.9
    beam_skip_threshold: 0.3
    do_beamskip: false
    global_frame_id: "map"
    lambda_short: 0.1
    laser_likelihood_max_dist: 0.5
    laser_max_range: 100.0
    laser_min_range: -1.0
    laser_model_type: "likelihood_field"
    max_beams: 60
    max_particles: 1300
    min_particles: 300
    odom_frame_id: "odom"
    pf_err: 0.05
    pf_z: 0.99
    recovery_alpha_fast: 0.0
    recovery_alpha_slow: 0.0
    resample_interval: 1
    robot_model_type: "nav2_amcl::OmniMotionModel"
    save_pose_rate: 0.5
    sigma_hit: 0.2
    tf_broadcast: true
    transform_tolerance: 1.0
    update_min_a: 0.1
    update_min_d: 0.2
    z_hit: 0.5
    z_max: 0.05
    z_rand: 0.5
    z_short: 0.05
    scan_topic: scan

bt_navigator:
  ros__parameters:
    use_sim_time: False
    global_frame: map
    robot_base_frame: base_link
    odom_topic: /odom
    bt_loop_duration: 10
    default_server_timeout: 20
    transform_tolerance: 1.0
    navigators: ['navigate_to_pose', 'navigate_through_poses']
    navigate_to_pose:
      plugin: "nav2_bt_navigator::NavigateToPoseNavigator"
    navigate_through_poses:
      plugin: "nav2_bt_navigator::NavigateThroughPosesNavigator"
    plugin_lib_names:
      - nav2_compute_path_to_pose_action_bt_node
      - nav2_compute_path_through_poses_action_bt_node
      - nav2_smooth_path_action_bt_node
      - nav2_follow_path_action_bt_node
      - nav2_spin_action_bt_node
      - nav2_wait_action_bt_node
      - nav2_assisted_teleop_action_bt_node
      - nav2_back_up_action_bt_node
      - nav2_drive_on_heading_bt_node
      - nav2_clear_costmap_service_bt_node
      - nav2_is_stuck_condition_bt_node
      - nav2_goal_reached_condition_bt_node
      - nav2_goal_updated_condition_bt_node
      - nav2_globally_updated_goal_condition_bt_node
      - nav2_is_path_valid_condition_bt_node
      - nav2_initial_pose_received_condition_bt_node
      - nav2_reinitialize_global_localization_service_bt_node
      - nav2_rate_controller_bt_node
      - nav2_distance_controller_bt_node
      - nav2_speed_controller_bt_node
      - nav2_truncate_path_action_bt_node
      - nav2_truncate_path_local_action_bt_node
      - nav2_goal_updater_node_bt_node
      - nav2_recovery_node_bt_node
      - nav2_pipeline_sequence_bt_node
      - nav2_round_robin_node_bt_node
      - nav2_transform_available_condition_bt_node
      - nav2_time_expired_condition_bt_node
      - nav2_path_expiring_timer_condition
      - nav2_distance_traveled_condition_bt_node
      - nav2_single_trigger_bt_node
      - nav2_is_battery_low_condition_bt_node
      - nav2_navigate_through_poses_action_bt_node
      - nav2_navigate_to_pose_action_bt_node
      - nav2_remove_passed_goals_action_bt_node
      - nav2_planner_selector_bt_node
      - nav2_controller_selector_bt_node
      - nav2_goal_checker_selector_bt_node
      - nav2_controller_cancel_bt_node
      - nav2_path_longer_on_approach_bt_node
      - nav2_wait_cancel_bt_node
      - nav2_spin_cancel_bt_node
      - nav2_back_up_cancel_bt_node
      - nav2_assisted_teleop_cancel_bt_node
      - nav2_drive_on_heading_cancel_bt_node
    error_code_names:
      - compute_path_error_code
      - follow_path_error_code

bt_navigator_navigate_through_poses_rclcpp_node:
  ros__parameters:
    use_sim_time: False

bt_navigator_navigate_to_pose_rclcpp_node:
  ros__parameters:
    use_sim_time: False
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

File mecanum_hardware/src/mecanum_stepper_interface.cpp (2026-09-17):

#include "mecanum_hardware/mecanum_stepper_interface.hpp"

#include <chrono>
#include <cmath>
#include <sstream>
#include <iomanip>

// Serial communication
#include <fcntl.h>
#include <termios.h>
#include <unistd.h>

#include "hardware_interface/types/hardware_interface_type_values.hpp"
#include "rclcpp/rclcpp.hpp"

namespace mecanum_hardware
{

hardware_interface::CallbackReturn MecanumStepperInterface::on_init(
  const hardware_interface::HardwareInfo & info)
{
  if (
    hardware_interface::SystemInterface::on_init(info) !=
    hardware_interface::CallbackReturn::SUCCESS)
  {
    return hardware_interface::CallbackReturn::ERROR;
  }
  
  // Initialize steady clock
  steady_clock_ = std::make_shared<rclcpp::Clock>(RCL_STEADY_TIME);

  //stepper parameters
  steps_per_revolution_ = std::stod(info_.hardware_parameters["steps_per_revolution"]);
  wheel_radius_ = std::stod(info_.hardware_parameters["wheel_radius"]);
  gear_ratio_ = std::stod(info_.hardware_parameters.count("gear_ratio") ? 
                          info_.hardware_parameters["gear_ratio"] : "1.0");
  
  // Get robot dimensions (for mecanum kinematics)
  wheel_separation_x_ = std::stod(info_.hardware_parameters.count("wheel_separation_x") ?
                                  info_.hardware_parameters["wheel_separation_x"] : "0.25");
  wheel_separation_y_ = std::stod(info_.hardware_parameters.count("wheel_separation_y") ?
                                  info_.hardware_parameters["wheel_separation_y"] : "0.30");
  
  // Get IMU usage
  use_imu_ = info_.hardware_parameters.count("use_imu") && 
             info_.hardware_parameters["use_imu"] == "true";
  
  RCLCPP_INFO(
    rclcpp::get_logger("MecanumStepperInterface"),
    "Stepper params: steps/rev=%.0f, wheel_r=%.3f, gear_ratio=%.2f, use_imu=%s",
    steps_per_revolution_, wheel_radius_, gear_ratio_, use_imu_ ? "true" : "false");

  // Setup ESP connections (2 ESPs)
  // ESP1: FL (index 0), FR (index 1)
  // ESP2: BL (index 2), BR (index 3)
  
  // Setup ESP32 connections
  ESPConnection esp1;
  esp1.port = info_.hardware_parameters["esp1_port"];
  esp1.baudrate = info_.hardware_parameters.count("esp_baudrate") ? 
                  std::stoi(info_.hardware_parameters["esp_baudrate"]) : 115200;
  esp1.motor_indices = {0, 1};  // Front left, Front right
  esp_connections_.push_back(esp1);
  
  ESPConnection esp2;
  esp2.port = info_.hardware_parameters["esp2_port"];
  esp2.baudrate = esp1.baudrate;  // Use same baudrate as ESP1
  esp2.motor_indices = {2, 3};  // Back left, Back right
  esp_connections_.push_back(esp2);
  
  RCLCPP_INFO(
    rclcpp::get_logger("MecanumStepperInterface"),
    "ESP1: %s (FL, FR) | ESP2: %s (BL, BR)",
    esp1.port.c_str(), esp2.port.c_str());

  // Initialize wheel data structures (4 wheels)
  wheel_names_.resize(info_.joints.size());
  hw_commands_velocity_.resize(info_.joints.size(), 0.0);
  hw_states_position_.resize(info_.joints.size(), 0.0);
  hw_states_velocity_.resize(info_.joints.size(), 0.0);

  for (size_t i = 0; i < info_.joints.size(); i++) {
    wheel_names_[i] = info_.joints[i].name;
    RCLCPP_INFO(
      rclcpp::get_logger("MecanumStepperInterface"),
      "Joint %zu: %s", i, wheel_names_[i].c_str());
  }
  
  first_read_ = true;
  imu_angular_velocity_z_ = 0.0;
  last_slip_warning_time_ = std::chrono::steady_clock::now();
  last_write_warning_time_ = std::chrono::steady_clock::now();

  // Create IMU subscriber if enabled
  // a python node is there which works
  if (use_imu_) {
    RCLCPP_INFO(
      rclcpp::get_logger("MecanumStepperInterface"),
      "IMU fusion enabled - will subscribe to /imu/data");
  }

  return hardware_interface::CallbackReturn::SUCCESS;
}

hardware_interface::CallbackReturn MecanumStepperInterface::on_configure(
  const rclcpp_lifecycle::State & /*previous_state*/)
{
  RCLCPP_INFO(rclcpp::get_logger("MecanumStepperInterface"), "Configuring...");
  
  // Open both ESP connections
  for (auto& esp : esp_connections_) {
    if (!open_esp_port(esp)) {
      RCLCPP_ERROR(
        rclcpp::get_logger("MecanumStepperInterface"),
        "Failed to open ESP port: %s", esp.port.c_str());
      return hardware_interface::CallbackReturn::ERROR;
    }
    RCLCPP_INFO(
      rclcpp::get_logger("MecanumStepperInterface"),
      "Opened ESP port: %s @ %d baud", esp.port.c_str(), esp.baudrate);
  }
  
  // NOTE: Hardware interface should NOT create its own ROS node
  // IMU data is handled by separate IMU publisher node
  // Cartographer handles sensor fusion at higher level
  // Hardware interface only reports pure wheel odometry
  if (use_imu_) {
    RCLCPP_INFO(rclcpp::get_logger("MecanumStepperInterface"), 
                "IMU enabled - Cartographer will handle sensor fusion");
  }
  
  RCLCPP_INFO(rclcpp::get_logger("MecanumStepperInterface"), 
              "Successfully configured!");
  return hardware_interface::CallbackReturn::SUCCESS;
}

std::vector<hardware_interface::StateInterface>
MecanumStepperInterface::export_state_interfaces()
{
  std::vector<hardware_interface::StateInterface> state_interfaces;
  
  for (size_t i = 0; i < info_.joints.size(); i++) {
    state_interfaces.emplace_back(
      hardware_interface::StateInterface(
        wheel_names_[i], 
        hardware_interface::HW_IF_POSITION, 
        &hw_states_position_[i]));
    state_interfaces.emplace_back(
      hardware_interface::StateInterface(
        wheel_names_[i], 
        hardware_interface::HW_IF_VELOCITY, 
        &hw_states_velocity_[i]));
  }
  
  return state_interfaces;
}

std::vector<hardware_interface::CommandInterface>
MecanumStepperInterface::export_command_interfaces()
{
  std::vector<hardware_interface::CommandInterface> command_interfaces;
  
  for (size_t i = 0; i < info_.joints.size(); i++) {
    command_interfaces.emplace_back(
      hardware_interface::CommandInterface(
        wheel_names_[i], 
        hardware_interface::HW_IF_VELOCITY, 
        &hw_commands_velocity_[i]));
  }
  
  return command_interfaces;
}

hardware_interface::CallbackReturn MecanumStepperInterface::on_activate(
  const rclcpp_lifecycle::State & /*previous_state*/)
{
  RCLCPP_INFO(rclcpp::get_logger("MecanumStepperInterface"), "Activating...");
  
  // Send zero velocity to all motors
  std::vector<double> zero_cmd = {0.0, 0.0};
  for (auto& esp : esp_connections_) {
    send_velocity_command(esp, zero_cmd);
  }
  
  first_read_ = true;
  
  RCLCPP_INFO(rclcpp::get_logger("MecanumStepperInterface"), 
              "Successfully activated!");
  return hardware_interface::CallbackReturn::SUCCESS;
}
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

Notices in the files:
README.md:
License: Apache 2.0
